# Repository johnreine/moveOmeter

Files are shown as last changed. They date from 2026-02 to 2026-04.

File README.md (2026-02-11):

# moveOmeter

### Privacy-Preserving IoT Monitoring for Elderly Care

> Help your loved ones live independently longer with non-invasive, radar-based health monitoring.






---

## 🎯 The Problem

Families want to care for aging loved ones while respecting their independence and privacy. Traditional monitoring requires cameras (invasive) or wearables (forgotten/rejected).

## 💡 Our Solution

**moveOmeter** uses mmWave radar technology to monitor health and activity patterns without cameras or wearables. The system tracks:

- 🚶 **Activity & Movement** - Daily patterns and mobility changes
- 😴 **Sleep Quality** - Duration, disturbances, and sleep score
- ❤️ **Vital Signs** - Heart rate and respiration (contactless)
- 🚨 **Fall Detection** - Instant alerts for falls or emergencies
- 🏠 **Presence Detection** - Know when they're home or away

**No cameras. No wearables. No user interaction required.**

---

## ✨ Key Features

### Privacy-First Design
- ✅ Radar technology (sees motion, not images)
- ✅ No video, no photos, no recording
- ✅ HIPAA-compliant architecture ready

### Real-Time Monitoring
- ✅ Live web dashboard with charts
- ✅ Mobile-responsive interface
- ✅ Instant WebSocket updates
- ✅ Historical trend analysis

### Smart & Adaptive
- ✅ Learns individual patterns
- ✅ Detects anomalies automatically
- ✅ Over-the-air firmware updates
- ✅ Remote configuration

### Secure & Scalable
- ✅ Role-based access control (admin/employee/caretaker/resident)
- ✅ End-to-end encryption
- ✅ Audit logging
- ✅ Designed to scale to millions of users

---

## 📸 Screenshots

### Real-Time Dashboard
> 🚧 *Screenshot coming soon - see [deployment guide](./deployment/QUICKSTART.md) to run locally*

**Features visible in dashboard:**
- Live timeline charts (1-hour, 12-hour, 24-hour views)
- Activity metrics (movement, presence, sleep quality)
- Device status (online/offline)
- Manual annotations
- Alert notifications

### Admin Panel
> 🚧 *Screenshot coming soon*

**Manage users and devices:**
- User management (create, edit, roles)
- Device assignment
- Access control
- Audit logs

---

## 🚀 Quick Start

### Prerequisites
- ESP32-C6 Feather development board
- DFRobot SEN0623 mmWave sensor
- Supabase account (free tier works)
- Arduino IDE 2.x

### 5-Minute Setup

1. **Clone the repository**
   ```bash
   git clone https://github.com/johnreine/moveOmeter.git
   cd moveOmeter
   ```

2. **Set up database**
   - Create Supabase project at https://supabase.com
   - Run migrations: `database/run_all_migrations.sql`

3. **Configure firmware**
   ```bash
   # Edit pictureFrame/software/mmWave_Supabase_collector/config.h
   # Add your WiFi credentials and Supabase URL/key
   ```

4. **Upload to ESP32-C6**
   - Open Arduino IDE
   - Select board: ESP32C6 Dev Module
   - Upload sketch

5. **Start dashboard**
   ```bash
   cd web/dashboard
   python3 -m http.server 8000
   open http://localhost:8000
   ```

**Full setup guide:** [deployment/QUICKSTART.md](./deployment/QUICKSTART.md)

---

## 🏗️ Architecture

```
┌──────────────────────────────────────────────────────┐
│  ESP32-C6 + mmWave Sensor (DFRobot SEN0623)         │
│  • Collects 40+ health metrics every 20 seconds     │
│  • WiFi upload to cloud                             │
│  • OTA firmware updates                             │
└─────────────────┬────────────────────────────────────┘
                  │ HTTPS Upload
                  ▼
┌──────────────────────────────────────────────────────┐
│  Supabase Backend (PostgreSQL + Auth + Realtime)    │
│  • Time-series sensor data storage                  │
│  • Role-based access control (RLS)                  │
│  • Real-time WebSocket subscriptions                │
│  • OTA firmware distribution                        │
└─────────────────┬────────────────────────────────────┘
                  │ WebSocket + REST API
                  ▼
┌──────────────────────────────────────────────────────┐
│  Web Dashboard (Vanilla JS + Chart.js)              │
│  • Live charts and metrics                          │
│  • User authentication                              │
│  • Admin panel                                      │
│  • Mobile responsive                                │
└──────────────────────────────────────────────────────┘
```

---

## 🛠️ Tech Stack

### Hardware



### Backend



### Frontend




### Firmware



### Deployment



---

## 📚 Documentation

| Document | Description |
|---|---|
| **[Project Status](./PROJECT_STATUS.md)** | Complete overview of features and progress |
| **[Development Roadmap](./ROADMAP.md)** | 6-12 month development plan |
| **[AI Agent Guide](./AI_AGENT_GUIDE.md)** | For AI coding assistants (Claude, GPT, etc.) |
| **[Quick Start](./deployment/QUICKSTART.md)** | Get running in 5 minutes |
| **[Full Deployment Guide](./deployment/README.md)** | Production deployment instructions |
| **[Authentication Setup](./web/dashboard/AUTH_SETUP.md)** | User management and security |
| **[Firmware README](./pictureFrame/software/mmWave_Supabase_collector/README.md)** | ESP32-C6 firmware details |
| **[OTA Testing Guide](./database/OTA_QUICK_TEST.md)** | Test firmware updates |

---

## 🗺️ Roadmap

### ✅ Current (v1.0) - Complete
- ESP32-C6 firmware with dual collection modes
- Real-time web dashboard with charts
- Authentication system (4 user roles)
- Admin panel for user/device management
- OTA firmware update infrastructure
- Timeline annotations
- Data aggregation for performance

### 🚧 Next Month (v1.1)
- [ ] Multi-device support in dashboard
- [ ] Progressive Web App (PWA)
- [ ] Email notifications
- [ ] Activity summary reports
- [ ] Mobile-responsive design improvements

### 🔮 Next Quarter (v1.5)
- [ ] React Native mobile app (iOS + Android)
- [ ] Predictive health alerts (ML-based)
- [ ] Medication reminder integration
- [ ] Voice integration (Alexa/Google Home)
- [ ] Family sharing features

### 🎯 Long-Term Vision
- AI-powered gait analysis and fall risk prediction
- Behavior pattern recognition
- White-label solution for senior living facilities
- Integration ecosystem (Apple Health, etc.)

**Full roadmap:** [ROADMAP.md](./ROADMAP.md)

---

## 🤝 Contributing

We welcome contributions! This project is currently in active development.

### How to Contribute

1. **Read the docs**
   - [Project Status](./PROJECT_STATUS.md) - Current state
   - [Roadmap](./ROADMAP.md) - Planned features
   - [AI Agent Guide](./AI_AGENT_GUIDE.md) - Technical details

2. **Find an issue**
   - Check [Issues](https://github.com/johnreine/moveOmeter/issues) for open tasks
   - Look for `good first issue` or `help wanted` labels

3. **Fork and create a branch**
   ```bash
   git checkout -b feature/your-feature-name
   ```

4. **Make your changes**
   - Follow existing code style
   - Add tests if applicable
   - Update documentation

5. **Submit a pull request**
   - Clear description of changes
   - Reference related issues
   - Screenshots for UI changes

### Development Setup

```bash
# Clone repository
git clone https://github.com/johnreine/moveOmeter.git
cd moveOmeter

# Install Arduino libraries
# - ESPSupabase (by jhagas)
# - DFRobot_HumanDetection (by DFRobot)

# Set up Supabase
# 1. Create account at https://supabase.com
# 2. Run database/run_all_migrations.sql

# Start local dashboard
cd web/dashboard
python3 -m http.server 8000
```

### Code Style

- **JavaScript:** ES6+, async/await, template literals
- **C++:** Arduino style, comments for complex logic
- **SQL:** Uppercase keywords, clear comments
- **Documentation:** Markdown with clear headings

---

## 🌟 Use Cases

### For Families
- Monitor aging parents remotely
- Peace of mind while at work
- Early detection of health changes
- Respect privacy (no cameras)

### For Caregivers
- Track multiple clients
- Shift handoff notes
- Medication reminders
- Fall alerts

### For Senior Living Facilities
- Monitor all residents
- Staff coordination
- Compliance reporting
- Emergency response

### For Healthcare Providers
- Remote patient monitoring
- Post-discharge tracking
- Chronic condition management
- Reduce hospital readmissions

---

## 📊 Project Stats

- **40 files** of comprehensive documentation
- **16,000+ lines** of code and docs
- **40+ sensor metrics** collected
- **4 user roles** with granular permissions
- **3 timeline views** (1h, 12h, 24h)
- **97% bandwidth reduction** with smart keep-alive
- **OTA updates** for remote firmware deployment

---

## 🔐 Security & Privacy

### Privacy Protections
- ✅ No cameras or video recording
- ✅ Radar technology (motion only, not images)
- ✅ Data encrypted in transit (HTTPS)
- ✅ Data encrypted at rest (Supabase)
- ✅ Row Level Security (RLS) for data isolation

### Compliance Ready
- 🔜 HIPAA compliance architecture
- 🔜 GDPR data handling
- 🔜 SOC 2 Type II準備中

### Security Features
- Multi-factor authentication (MFA) support
- Passkey/WebAuthn ready
- Audit logging for all actions
- Role-based access control
- Automatic session management

---

## 🛡️ Testing

### Current Test Coverage
- ✅ End-to-end firmware testing
- ✅ Real-time data pipeline
- ✅ Authentication flows
- ✅ Role-based access control
- 🚧 Cross-browser compatibility
- 🚧 Scale testing (100-1000 devices)

### Tested Environments
- **Firmware:** ESP32-C6 Feather
- **Browsers:** Chrome, Firefox, Safari (desktop)
- **Database:** Supabase (PostgreSQL 15)
- **Deployment:** Ubuntu 22.04 + Nginx

---

## 💰 Cost to Run

### Development (Current)
- **Supabase:** Free tier (good for 10 devices)
- **Digital Ocean:** $10-20/month
- **Total:** ~$10-20/month

### Small Deployment (100 devices)
- **Supabase:** $25/month (Pro tier)
- **Digital Ocean:** $20/month
- **Total:** ~$45/month

### Medium Scale (1,000 devices)
- **Supabase:** $599/month (Team tier)
- **Digital Ocean/AWS:** $100-200/month
- **Total:** ~$700-800/month

**Note:** Costs scale linearly. See [ROADMAP.md](./ROADMAP.md) for scaling details.

---

## 📄 License

**Proprietary** - All rights reserved.

This project is currently not open source. Contact for licensing inquiries.

---

## 📞 Contact & Support

### Questions or Issues?
1. Check [Project Status](./PROJECT_STATUS.md) and [Roadmap](./ROADMAP.md)
2. Review [documentation](./deployment/README.md)
3. Open an [Issue](https://github.com/johnreine/moveOmeter/issues)

### Business Inquiries
- **Email:** contact@moveometer.com (TBD)
- **Website:** https://moveometer.com (TBD)

### For Contributors
- Join discussions in [Issues](https://github.com/johnreine/moveOmeter/issues)
- Submit [Pull Requests](https://github.com/johnreine/moveOmeter/pulls)
- See [AI Agent Guide](./AI_AGENT_GUIDE.md) for technical details

---

## 🙏 Acknowledgments

### Hardware
- **Adafruit** - ESP32-C6 Feather development board
- **DFRobot** - SEN0623 mmWave sensor

### Software & Services
- **Supabase** - Backend-as-a-Service platform
- **Chart.js** - Beautiful data visualization
- **Arduino** - ESP32 development framework

### Inspiration
Built with care for families supporting elderly loved ones. Inspired by the need for privacy-preserving health monitoring that maintains dignity and independence.

---

## ⭐ Star History

If you find this project useful, consider giving it a star! ⭐

---

## 📈 Project Activity




---

<div align="center">

**Made with ❤️ for better elderly care**

[Documentation](./PROJECT_STATUS.md) • [Roadmap](./ROADMAP.md) • [Contributing](#contributing) • [License](#license)

</div>

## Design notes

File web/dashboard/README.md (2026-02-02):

# moveOmeter Real-Time Dashboard

Beautiful web-based dashboard for visualizing mmWave sensor data in real-time.

## Features

- 📊 **Live Charts** - Heart rate, respiration, presence, and sleep quality
- 🔴 **Real-Time Updates** - Automatic updates via Supabase Realtime
- ⚠️ **Alerts** - Visual warnings for apnea events, struggles, and unusual activity
- 📱 **Responsive Design** - Works on desktop, tablet, and mobile
- 🎨 **Beautiful UI** - Modern gradient design with smooth animations

## Quick Start

### Option 1: Simple File Open (Easiest)

1. Open `index.html` directly in your web browser:
   ```bash
   open index.html
   ```
   Or just double-click `index.html` in Finder

2. The dashboard will connect to your Supabase database automatically

**Note:** Real-time updates might not work with `file://` protocol. Use Option 2 for full functionality.

### Option 2: Local Web Server (Recommended)

Using Python 3:
```bash
cd /Users/johnreine/Dropbox/john/2025_work/moveOmeter/web/dashboard
python3 -m http.server 8000
```

Then open: http://localhost:8000

### Option 3: Using Node.js

```bash
npx http-server -p 8000
```

Then open: http://localhost:8000

## Configuration

Edit `config.js` to customize:

```javascript
// Device to monitor (set to null to show all devices)
deviceId: 'ESP32C6_001',

// How often to refresh data (milliseconds)
refreshInterval: 5000,

// Number of data points to show in charts
maxDataPoints: 20
```

## Dashboard Sections

### Current Metrics (Top Cards)
- **Heart Rate** - Real-time heart rate in BPM
- **Respiration** - Breaths per minute
- **Presence** - Is person detected?
- **In Bed** - Current bed occupancy
- **Sleep Quality** - Overall sleep quality score (0-100)
- **Apnea Events** - Count of breathing pause events

### Charts
1. **Heart Rate** - Line chart showing heart rate over last 20 readings
2. **Respiration Rate** - Breathing pattern visualization
3. **Presence & Movement** - Dual-axis chart showing detection and movement intensity
4. **Sleep Quality** - Bar chart of sleep quality scores over time

### Alerts
Automatic alerts appear for:
- 🚨 Apnea events (breathing stopped)
- ⚠️ Abnormal struggle detected
- 🛏️ Out of bed during night hours (10pm-6am)
- 👤 Person left monitored area

## Real-Time Updates

The dashboard uses **Supabase Realtime** to automatically update when new data arrives from your ESP32-C6 device. No page refresh needed!

How it works:
1. ESP32-C6 inserts new row into Supabase table
2. Supabase broadcasts change via WebSocket
3. Dashboard receives update instantly
4. Charts and metrics update automatically

## Troubleshooting

### Dashboard shows "Disconnected"
- Check that Supabase URL and anon key are correct in `config.js`
- Verify the table name matches your database
- Check browser console (F12) for error messages

### No data appears
- Verify ESP32-C6 is running and uploading data
- Check Supabase table has data: `SELECT * FROM mmwave_sensor_data LIMIT 10;`
- Confirm `deviceId` in `config.js` matches your device

### Charts not updating
- Ensure you're using a web server (Option 2 or 3), not `file://`
- Check browser console for WebSocket connection errors
- Try refreshing the page

### Real-time not working
- Supabase Realtime requires Row Level Security to be properly configured
- Verify the table has RLS policies allowing reads
- Check your Supabase project has Realtime enabled

## Customization

### Change Color Scheme
Edit the CSS in `index.html`:
```css
background: linear-gradient(135deg, #667eea 0%, #764ba2 100%);
```

### Add More Charts
1. Add a new canvas element in `index.html`:
   ```html
   <canvas id="myNewChart"></canvas>
   ```

2. Initialize the chart in `dashboard.js`:
   ```javascript
   charts.myNew = new Chart(document.getElementById('myNewChart'), {
       // Chart configuration
   });
   ```

3. Update the chart in the `updateCharts()` function

### Modify Alert Conditions
Edit the `checkAlerts()` function in `dashboard.js` to add custom alert logic.

## Deployment

### Deploy to Static Hosting

**Netlify:**
```bash
# Install Netlify CLI
npm install -g netlify-cli

# Deploy
cd /Users/johnreine/Dropbox/john/2025_work/moveOmeter/web/dashboard
netlify deploy --prod
```

**Vercel:**
```bash
# Install Vercel CLI
npm install -g vercel

# Deploy
cd /Users/johnreine/Dropbox/john/2025_work/moveOmeter/web/dashboard
vercel --prod
```

**GitHub Pages:**
1. Create a GitHub repository
2. Push the `web/dashboard` folder
3. Enable GitHub Pages in repository settings

### Security Considerations

⚠️ **IMPORTANT:** The `config.js` file contains your Supabase anon key. This is safe for client-side use, but:

1. **Enable Row Level Security (RLS)** on your Supabase table
2. **Never use the service_role key** in client-side code
3. For production, consider using environment variables with a build step

## Performance Tips

- **Reduce `maxDataPoints`** if charts feel sluggish (try 10-15)
- **Increase `refreshInterval`** if you don't need sub-second updates
- **Use specific `deviceId`** to filter data for better performance

## Browser Support

Works on all modern browsers:
- ✅ Chrome/Edge (recommended)
- ✅ Firefox
- ✅ Safari
- ✅ Mobile browsers (iOS Safari, Chrome Mobile)

Requires JavaScript enabled.

## Next Steps

1. **Add authentication** - Require login to view dashboard
2. **Historical data view** - Add date picker to view past data
3. **Export functionality** - Download data as CSV/PDF
4. **Mobile app** - Convert to React Native or Flutter app
5. **Notifications** - Add push notifications for critical alerts

## Files

- `index.html` - Main dashboard page
- `dashboard.js` - Chart logic and data fetching
- `config.js` - Configuration (Supabase credentials)
- `README.md` - This file

## License

Part of the moveOmeter IoT elderly monitoring project.

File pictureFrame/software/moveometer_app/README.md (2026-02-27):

# moveometer_app

A new Flutter project.

## Getting Started

This project is a starting point for a Flutter application.

A few resources to get you started if this is your first Flutter project:

- [Lab: Write your first Flutter app](https://docs.flutter.dev/get-started/codelab)
- [Cookbook: Useful Flutter samples](https://docs.flutter.dev/cookbook)

For help getting started with Flutter development, view the
[online documentation](https://docs.flutter.dev/), which offers tutorials,
samples, guidance on mobile development, and a full API reference.

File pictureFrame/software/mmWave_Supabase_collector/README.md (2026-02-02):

# mmWave Supabase Data Collector

Complete IoT solution for collecting mmWave sensor data and uploading to Supabase in real-time.

## Features

- ✅ Collects 40+ data fields from SEN0623 mmWave sensor
- ✅ WiFi connectivity with auto-reconnect
- ✅ Direct upload to Supabase using ESPSupabase library
- ✅ Automatic retry logic for failed uploads
- ✅ JSON formatted data
- ✅ Configurable collection intervals
- ✅ Sleep Mode optimized for elderly monitoring

## Quick Start

### 1. Install Required Libraries

Open Arduino IDE → Tools → Manage Libraries, then install:
- **ESPSupabase** by jhagas
- **DFRobot_HumanDetection** by DFRobot

### 2. Configure Your Settings

Edit `config.h` and set:

```cpp
// WiFi credentials
#define WIFI_SSID "your_wifi_network"
#define WIFI_PASSWORD "your_wifi_password"

// Supabase settings (from your Supabase dashboard)
#define SUPABASE_URL "https://xxxxx.supabase.co"
#define SUPABASE_ANON_KEY "eyJhbGc..."

// Database table name
#define SUPABASE_TABLE "mmwave_sensor_data"

// Device identification
#define DEVICE_ID "ESP32C6_001"
#define LOCATION "bedroom_1"
```

### 3. Create Supabase Table

In your Supabase dashboard, run this SQL:

```sql
CREATE TABLE mmwave_sensor_data (
  id BIGSERIAL PRIMARY KEY,
  created_at TIMESTAMPTZ DEFAULT NOW(),

  -- Metadata
  device_id TEXT NOT NULL,
  location TEXT,
  uptime_sec INTEGER,

  -- Human Presence & Movement
  human_presence INTEGER,
  human_movement INTEGER,
  moving_range INTEGER,
  distance_cm INTEGER,

  -- Vital Signs
  heart_rate_bpm INTEGER,
  respiration_rate INTEGER,
  respiration_state INTEGER,

  -- Sleep Status
  in_bed INTEGER,
  sleep_state INTEGER,
  wake_duration_min INTEGER,
  light_sleep_min INTEGER,
  deep_sleep_min INTEGER,
  sleep_quality INTEGER,
  sleep_disturbances INTEGER,
  sleep_quality_rating INTEGER,

  -- Abnormal Events
  abnormal_struggle INTEGER,
  unattended_state INTEGER,

  -- Sleep Composite Data
  composite_presence INTEGER,
  composite_sleep_state INTEGER,
  composite_avg_respiration INTEGER,
  composite_avg_heartbeat INTEGER,
  composite_turnover_count INTEGER,
  composite_large_body_move_pct INTEGER,
  composite_minor_body_move_pct INTEGER,
  composite_apnea_events INTEGER,

  -- Sleep Statistics
  stats_sleep_quality_score INTEGER,
  stats_sleep_time_min INTEGER,
  stats_wake_duration_min INTEGER,
  stats_shallow_sleep_pct INTEGER,
  stats_deep_sleep_pct INTEGER,
  stats_time_out_of_bed_min INTEGER,
  stats_exit_count INTEGER,
  stats_turnover_count INTEGER,
  stats_avg_respiration INTEGER,
  stats_avg_heartbeat INTEGER,
  stats_apnea_events INTEGER
);

-- Create indexes for better query performance
CREATE INDEX idx_device_created ON mmwave_sensor_data(device_id, created_at DESC);
CREATE INDEX idx_location ON mmwave_sensor_data(location);
CREATE INDEX idx_presence ON mmwave_sensor_data(human_presence, created_at DESC);
```

### 4. Get Your Supabase Credentials

1. Go to your Supabase project dashboard
2. Click **Settings** → **API**
3. Copy:
   - **Project URL** → paste into `SUPABASE_URL`
   - **anon/public key** → paste into `SUPABASE_ANON_KEY`

### 5. Upload and Run

1. Connect ESP32-C6 to your computer
2. Select board: **ESP32C6 Dev Module**
3. Select port
4. Upload the sketch
5. Open Serial Monitor at 115200 baud

## Expected Output

```
=================================
mmWave Supabase Data Collector
=================================
Connecting to WiFi: MyNetwork... CONNECTED!
IP Address: 192.168.1.100
Initializing Supabase... SUCCESS!
Initializing sensor (this takes ~10 seconds)... SUCCESS!
Configuring Sleep Mode... SUCCESS!
=================================
System ready! Collecting data...

Data collected:
{"device_id":"ESP32C6_001","location":"bedroom_1",...}
Uploading to Supabase... SUCCESS!
```

## Data Fields Reference

### Vital Signs
- **heart_rate_bpm**: Heart rate in beats per minute (0-255)
- **respiration_rate**: Breaths per minute (0-255)
- **respiration_state**: 1=normal, 2=too fast, 3=too slow, 4=none

### Sleep Metrics
- **in_bed**: 0=out of bed, 1=in bed
- **sleep_state**: Current sleep state code
- **sleep_quality**: Real-time sleep quality score
- **stats_sleep_quality_score**: Overall sleep quality (cumulative)
- **stats_sleep_time_min**: Total sleep duration in minutes
- **stats_shallow_sleep_pct**: Light sleep as percentage of total
- **stats_deep_sleep_pct**: Deep sleep as percentage of total

### Movement Detection
- **human_presence**: 0=absent, 1=present
- **human_movement**: Movement intensity (0-100)
- **moving_range**: Movement area coverage (0-100)
- **distance_cm**: Distance to detected person in centimeters

### Abnormal Events
- **abnormal_struggle**: Detected struggle or distress
- **composite_apnea_events**: Breathing pause events (sleep apnea)
- **stats_apnea_events**: Total apnea events (cumulative)
- **unattended_state**: Person has left the monitored area

### Sleep Analysis
- **composite_turnover_count**: Number of position changes
- **composite_large_body_move_pct**: Large movements as percentage
- **composite_minor_body_move_pct**: Small movements as percentage
- **stats_exit_count**: Times person got out of bed
- **stats_time_out_of_bed_min**: Total time spent out of bed

## Configuration Options

### Data Collection Interval

In `config.h`, adjust:
```cpp
#define DATA_INTERVAL 5000  // milliseconds (5 seconds default)
```

Recommendations:
- Real-time monitoring: 1000-5000 ms
- Battery optimization: 30000-60000 ms
- Long-term trends: 300000-900000 ms (5-15 minutes)

### Retry Settings

```cpp
#define RETRY_ATTEMPTS 3     // Number of upload retries
#define RETRY_DELAY 2000     // Delay between retries (ms)
```

## Troubleshooting

### WiFi Connection Failed
- Verify SSID and password in `config.h`
- Check that ESP32-C6 is within WiFi range
- Ensure 2.4GHz WiFi (ESP32-C6 doesn't support 5GHz)

### Supabase Upload Failed (HTTP 401)
- Check that `SUPABASE_ANON_KEY` is correct
- Verify table name matches `SUPABASE_TABLE`
- Check Supabase Row Level Security policies (disable for testing)

### Supabase Upload Failed (HTTP 404)
- Table name doesn't exist
- Check `SUPABASE_TABLE` spelling in `config.h`

### Sensor Initialization Failed
- Check wiring connections
- Verify 5V power supply
- Wait 10 seconds for sensor startup

### Data Looks Wrong
- Sensor needs ~30-60 seconds after startup to calibrate
- Movement data is only accurate when person is in detection range
- Sleep statistics accumulate over time (won't show immediately)

## Security Best Practices

### Protect Your Credentials

**IMPORTANT**: Never commit `config.h` to public repositories!

Add to `.gitignore`:
```
config.h
```

### Supabase Row Level Security

For production, enable RLS policies in Supabase:

```sql
-- Allow inserts from authenticated devices only
ALTER TABLE mmwave_sensor_data ENABLE ROW LEVEL SECURITY;

CREATE POLICY "Allow device inserts"
ON mmwave_sensor_data
FOR INSERT
WITH CHECK (auth.role() = 'anon');

-- Allow reads for authenticated users
CREATE POLICY "Allow authenticated reads"
ON mmwave_sensor_data
FOR SELECT
USING (auth.role() = 'authenticated');
```

## Next Steps

1. **Multiple Devices**: Clone and configure unique `DEVICE_ID` for each unit
2. **Data Visualization**: Build dashboards in Supabase or connect to Grafana
3. **Alerts**: Create edge functions to send notifications for abnormal events
4. **Battery Operation**: Add deep sleep between readings for battery power
5. **OTA Updates**: Implement over-the-air firmware updates

## Hardware Requirements

- ESP32-C6 Feather (or compatible board)
- DF Robot SEN0623 (C1001 mmWave sensor)
- 5V power supply (USB or dedicated)
- WiFi network (2.4GHz)

## Libraries Used

- **ESPSupabase** - [GitHub](https://github.com/jhagas/ESPSupabase)
- **DFRobot_HumanDetection** - [GitHub](https://github.com/DFRobot/DFRobot_HumanDetection)

## License

This is part of the moveOmeter IoT elderly monitoring project.

## Support

For issues or questions, refer to:
- [ESPSupabase Documentation](https://github.com/jhagas/ESPSupabase)
- [SEN0623 Wiki](https://wiki.dfrobot.com/SKU_SEN0623_C1001_mmWave_Human_Detection_Sensor)

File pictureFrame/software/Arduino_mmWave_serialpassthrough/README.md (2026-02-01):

# Arduino mmWave Serial Passthrough

Simple serial passthrough program for ESP32-C6 Feather to communicate with the DF Robot SEN0623 (C1001 mmWave Human Detection system).

## Purpose

This test program allows you to:
- View raw data from the mmWave sensor on your computer
- Send configuration commands to the mmWave sensor
- Verify the sensor is working correctly before integration

## Hardware Connections

Connect the DF Robot SEN0623 to the ESP32-C6 Feather:

| mmWave Sensor | ESP32-C6 Feather |
|---|---|
| TX | GPIO17 (RX) |
| RX | GPIO16 (TX) |
| GND | GND |
| VCC | 3.3V or 5V |

**Note:** Check the SEN0623 datasheet for proper voltage (3.3V or 5V).

## How to Use

1. **Upload the sketch**
   - Open `Arduino_mmWave_serialpassthrough.ino` in Arduino IDE
   - Select board: "ESP32C6 Dev Module" or "Adafruit Feather ESP32-C6"
   - Select the correct COM port
   - Click Upload

2. **Open Serial Monitor**
   - Set baud rate to **115200**
   - You should see the startup message
   - Data from the mmWave sensor will appear in the monitor

3. **Send commands to sensor**
   - Type commands in the Serial Monitor input field
   - Commands will be forwarded to the mmWave sensor
   - Sensor responses will appear in the monitor

## Configuration

If the mmWave sensor uses a different baud rate:
- Edit `MMWAVE_BAUD` in the sketch (line 27)
- Common values: 9600, 115200, 256000

## Troubleshooting

**No data appearing:**
- Check wiring connections
- Verify sensor power (LED should be on if present)
- Try different baud rates for MMWAVE_BAUD
- Confirm TX/RX are not swapped

**Garbled data:**
- Wrong baud rate - check sensor documentation
- Possible wiring issue or loose connection

**Cannot upload sketch:**
- Press and hold BOOT button while uploading
- Check USB cable supports data (not just charging)
- Verify correct board and port selected in Arduino IDE

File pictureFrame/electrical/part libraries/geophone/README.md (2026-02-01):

# SM-24 Geophone Front-End with ADS1220 ADC

## Circuit Overview

```
                                    +3.3V
                                      │
                                     ┌┴┐
                                R1   │ │ 100k
                                     └┬┘
     ┌─────────┐                      │
     │  SM-24  │    C1        VCC/2   │        R4 (100k)
     │ Geophone├────┤├────┬────●──────┼────────/\/\/────┐
     │         │  10µF    │           │                  │
     └────┬────┘         ┌┴┐          │    ┌─────┐       │
          │         R1   │ │ 100k     └────┤-  U1A├──────┴───┐
         GND             └┬┘               │  OPA │          │
                          │          ┌─────┤+    │          │
                         ┌┴┐         │     └─────┘          │
                    C2   │ │ 10µF    │                      │
                         └┬┘       VCC/2                    │
                          │          │                      │
                         GND        ┌┴┐                     │
                                R3  │ │ 1k                  │
                                    └┬┘                     │
                                     │                      │
                                    GND                     │
                                                            │
    ┌───────────────────────────────────────────────────────┘
    │
    │  Sallen-Key Low-Pass Filter (50Hz)
    │
    │     R5          R6
    └────/\/\/───┬───/\/\/───┬─────────┤+  U1B ├────┬─────► To ADC
        31.6k   │   31.6k   │         │  OPA  │    │       (AIN0)
               ┌┴┐         ┌┴┐   ┌────┤-     │    │
          C3   │ │100nF    │ │   │    └──────┘    │
               └┬┘         └┬┘   │                │
                │    C4     │    └────────────────┘
               GND        GND

    ADS1220 ADC Connections:
    ┌──────────────────────────────────────────┐
    │  ADS1220                                 │
    │                                          │
    │  AIN0 ◄──── Filter Output               │
    │  AIN1 ◄──── GND (differential ref)      │
    │                                          │
    │  REFP0 ◄─── AVDD (internal 2.048V ref)  │
    │  REFN0 ◄─── GND                         │
    │                                          │
    │  AVDD ◄──── +3.3V                       │
    │  DVDD ◄──── +3.3V                       │
    │  AVSS ◄──── GND                         │
    │  DGND ◄──── GND                         │
    │                                          │
    │  SCLK ────► MCU SPI Clock               │
    │  DOUT ────► MCU MISO                    │
    │  DIN  ◄──── MCU MOSI                    │
    │  CS   ◄──── MCU Chip Select             │
    │  DRDY ────► MCU (interrupt, optional)   │
    └──────────────────────────────────────────┘
```

## Design Parameters

| Parameter | Value | Notes |
|---|---|---|
| Supply Voltage | 3.3V | Single supply |
| First Stage Gain | 101x (40.1 dB) | 1 + R4/R3 = 1 + 100k/1k |
| Filter Cutoff | ~50 Hz | Sallen-Key 2nd order |
| Filter Q | 0.707 | Butterworth response |
| ADC Resolution | 24 bits | ADS1220 with PGA |
| Sample Rate | Up to 2000 SPS | Configurable |

## Bill of Materials

| Ref | Value | Package | Description | DigiKey P/N |
|-----|---|---|---|---|
| U1 | OPA2188 | SOIC-8 | Low-noise dual op-amp | 296-40058-1-ND |
| U2 | ADS1220 | TSSOP-16 | 24-bit delta-sigma ADC | 296-35377-1-ND |
| C1 | 10µF | 0805 | Input coupling | 1276-1096-1-ND |
| C2 | 10µF | 0805 | Bias bypass | 1276-1096-1-ND |
| C3 | 100nF | 0603 | Filter capacitor | 1276-1005-1-ND |
| C4 | 100nF | 0603 | Filter capacitor | 1276-1005-1-ND |
| C5 | 100µF | 1206 | Power supply bulk | 1276-6767-1-ND |
| C6 | 100nF | 0603 | Op-amp bypass | 1276-1005-1-ND |
| C7 | 100nF | 0603 | ADC AVDD bypass | 1276-1005-1-ND |
| C8 | 100nF | 0603 | ADC DVDD bypass | 1276-1005-1-ND |
| R1 | 100k | 0603 | Bias divider (top) | 311-100KHRCT-ND |
| R2 | 100k | 0603 | Bias divider (bottom) | 311-100KHRCT-ND |
| R3 | 1k | 0603 | Gain set resistor | 311-1.00KHRCT-ND |
| R4 | 100k | 0603 | Feedback resistor | 311-100KHRCT-ND |
| R5 | 31.6k | 0603 | Filter resistor | 311-31.6KHRCT-ND |
| R6 | 31.6k | 0603 | Filter resistor | 311-31.6KHRCT-ND |
| J1 | 1x2 | 2.54mm | Geophone connector | 952-2261-ND |
| J2 | 1x6 | 2.54mm | SPI connector | 952-2265-ND |
| J3 | 1x2 | 2.54mm | Power connector | 952-2261-ND |

## SPI Connector Pinout (J2)

| Pin | Signal | Description |
|-----|---|---|
| 1 | VCC | 3.3V supply |
| 2 | SCLK | SPI clock |
| 3 | MISO | SPI data out (DOUT) |
| 4 | MOSI | SPI data in (DIN) |
| 5 | CS | Chip select (active low) |
| 6 | GND | Ground |

## Component Selection Notes

### Op-Amp (OPA2188)
- Very low offset voltage (±25µV max)
- Low noise (8.8 nV/√Hz)
- Rail-to-rail output
- Alternatives: MCP6022 (cheaper), OPA1612 (lower noise)

### ADC (ADS1220)
- 24-bit resolution
- Built-in PGA (gains 1, 2, 4, 8, 16, 32, 64, 128)
- Internal 2.048V reference
- Up to 2000 SPS
- Differential inputs reduce common-mode noise

### Filter Component Calculations
For a 50Hz Butterworth low-pass filter with Q = 0.707:
```
fc = 1 / (2π × R × C × √2)
With R5 = R6 = 31.6k and C3 = C4 = 100nF:
fc = 1 / (2π × 31.6k × 100nF × 1.414) ≈ 50 Hz
```

## Arduino/ESP32 Code Example

```cpp
#include <SPI.h>

// ADS1220 registers and commands
#define ADS1220_CMD_RESET    0x06
#define ADS1220_CMD_START    0x08
#define ADS1220_CMD_RDATA    0x10
#define ADS1220_CMD_RREG     0x20
#define ADS1220_CMD_WREG     0x40

const int CS_PIN = 10;
const int DRDY_PIN = 9;

void setup() {
  Serial.begin(115200);
  SPI.begin();
  pinMode(CS_PIN, OUTPUT);
  pinMode(DRDY_PIN, INPUT);
  digitalWrite(CS_PIN, HIGH);
  
  // Reset ADS1220
  digitalWrite(CS_PIN, LOW);
  SPI.transfer(ADS1220_CMD_RESET);
  digitalWrite(CS_PIN, HIGH);
  delay(1);
  
  // Configure: AIN0/AIN1 differential, gain=1, 20SPS, internal ref
  digitalWrite(CS_PIN, LOW);
  SPI.transfer(ADS1220_CMD_WREG | 0x00); // Write starting at reg 0
  SPI.transfer(0x04);  // 4 bytes to write
  SPI.transfer(0x01);  // Reg0: AIN0/AIN1, gain=1, PGA enabled
  SPI.transfer(0x04);  // Reg1: 20 SPS, normal mode
  SPI.transfer(0x40);  // Reg2: Internal 2.048V reference
  SPI.transfer(0x00);  // Reg3: Default
  digitalWrite(CS_PIN, HIGH);
  
  // Start continuous conversion
  digitalWrite(CS_PIN, LOW);
  SPI.transfer(ADS1220_CMD_START);
  digitalWrite(CS_PIN, HIGH);
}

void loop() {
  // Wait for data ready
  while (digitalRead(DRDY_PIN) == HIGH);
  
  // Read 24-bit result
  digitalWrite(CS_PIN, LOW);
  SPI.transfer(ADS1220_CMD_RDATA);
  int32_t result = 0;
  result |= ((int32_t)SPI.transfer(0x00) << 16);
  result |= ((int32_t)SPI.transfer(0x00) << 8);
  result |= SPI.transfer(0x00);
  digitalWrite(CS_PIN, HIGH);
  
  // Sign extend 24-bit to 32-bit
  if (result & 0x800000) {
    result |= 0xFF000000;
  }
  
  // Convert to voltage (with 2.048V reference, gain=1)
  float voltage = (float)result * 2.048 / 8388608.0;
  
  Serial.println(voltage, 6);
  delay(50);  // ~20 Hz sample rate
}
```

## PCB Layout Tips

1. **Ground plane**: Use a solid ground plane on bottom layer
2. **Analog/digital separation**: Keep digital traces away from analog input
3. **Decoupling caps**: Place as close to IC pins as possible
4. **Input traces**: Keep short, away from digital signals
5. **Via placement**: Avoid vias in analog signal path
6. **Component placement**: Place in signal flow order (left to right)

## Adjustments for Your Application

**Higher sensitivity (weak signals):**
- Increase R4 to 220k for gain of ~221x (47 dB)
- Add second gain stage if needed

**Lower cutoff frequency (slower gait):**
- Increase R5, R6 to 68k for ~25 Hz cutoff
- Or increase C3, C4 to 220nF

**Higher sample rate:**
- Configure ADS1220 for 330 SPS or higher
- May need to adjust filter cutoff accordingly

**Battery operation:**
- OPA2188 has low quiescent current (~400µA)
- ADS1220 duty cycle mode for power savings

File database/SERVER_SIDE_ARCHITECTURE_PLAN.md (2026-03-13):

# Server-Side Architecture Plan
## Moving All Logic from Clients to Database

**Problem:** Clients (web dashboard and mobile app) are currently doing extensive data processing, status calculations, and business logic. This causes inconsistencies, bugs, and violates the principle that clients should just display data.

**Goal:** Move ALL logic to the server. Clients become read-only displays of pre-computed database values.

---

## Phase 1: Device Status Tracking

### 1.1 Database Schema Changes

**Add columns to `moveometers` table:**
```sql
ALTER TABLE moveometers ADD COLUMN IF NOT EXISTS
    connection_status VARCHAR(20) DEFAULT 'unknown', -- 'online', 'stale', 'offline', 'unknown'
    connection_status_updated_at TIMESTAMPTZ,
    seconds_since_last_data INTEGER,
    connection_quality_score INTEGER DEFAULT 0, -- 0-100
    last_data_received_at TIMESTAMPTZ; -- Auto-updated on each data insert
```

**Create device status history table:**
```sql
CREATE TABLE IF NOT EXISTS device_status_history (
    id UUID PRIMARY KEY DEFAULT gen_random_uuid(),
    device_id TEXT REFERENCES moveometers(device_id),
    status VARCHAR(20) NOT NULL, -- 'online', 'stale', 'offline'
    started_at TIMESTAMPTZ NOT NULL,
    ended_at TIMESTAMPTZ,
    duration_seconds INTEGER,
    created_at TIMESTAMPTZ DEFAULT NOW()
);

CREATE INDEX idx_device_status_history_device ON device_status_history(device_id, started_at DESC);
```

### 1.2 Database Function: Update Device Status

**Function runs on every data insert via trigger:**
```sql
CREATE OR REPLACE FUNCTION update_device_status()
RETURNS TRIGGER AS $$
DECLARE
    v_seconds_since_last INTEGER;
    v_new_status VARCHAR(20);
    v_old_status VARCHAR(20);
BEGIN
    -- Calculate seconds since last data
    v_seconds_since_last := EXTRACT(EPOCH FROM (NOW() - COALESCE(NEW.device_timestamp, NEW.created_at)));

    -- Determine new status based on thresholds
    IF v_seconds_since_last <= 20 THEN
        v_new_status := 'online';
    ELSIF v_seconds_since_last <= 60 THEN
        v_new_status := 'stale';
    ELSE
        v_new_status := 'offline';
    END IF;

    -- Get current status
    SELECT connection_status INTO v_old_status
    FROM moveometers
    WHERE device_id = NEW.device_id;

    -- Update device status
    UPDATE moveometers SET
        connection_status = v_new_status,
        connection_status_updated_at = NOW(),
        seconds_since_last_data = v_seconds_since_last,
        last_data_received_at = COALESCE(NEW.device_timestamp, NEW.created_at),
        connection_quality_score = CASE
            WHEN v_seconds_since_last <= 20 THEN 100
            WHEN v_seconds_since_last <= 60 THEN 70
            ELSE 0
        END
    WHERE device_id = NEW.device_id;

    -- Record status change in history
    IF v_old_status IS DISTINCT FROM v_new_status THEN
        -- End previous status period
        UPDATE device_status_history
        SET ended_at = NOW(),
            duration_seconds = EXTRACT(EPOCH FROM (NOW() - started_at))
        WHERE device_id = NEW.device_id
            AND ended_at IS NULL;

        -- Start new status period
        INSERT INTO device_status_history (device_id, status, started_at)
        VALUES (NEW.device_id, v_new_status, NOW());
    END IF;

    RETURN NEW;
END;
$$ LANGUAGE plpgsql;

-- Attach trigger to sensor data inserts
CREATE TRIGGER trigger_update_device_status
    AFTER INSERT ON mmwave_sensor_data
    FOR EACH ROW
    EXECUTE FUNCTION update_device_status();
```

### 1.3 Scheduled Job: Check for Stale Devices

**Runs every 30 seconds to update devices that haven't sent data:**
```sql
CREATE OR REPLACE FUNCTION check_stale_devices()
RETURNS void AS $$
DECLARE
    v_device RECORD;
    v_seconds_since_last INTEGER;
    v_new_status VARCHAR(20);
BEGIN
    FOR v_device IN
        SELECT device_id, connection_status, last_data_received_at
        FROM moveometers
        WHERE device_status = 'active'
    LOOP
        v_seconds_since_last := EXTRACT(EPOCH FROM (NOW() - v_device.last_data_received_at));

        IF v_seconds_since_last <= 20 THEN
            v_new_status := 'online';
        ELSIF v_seconds_since_last <= 60 THEN
            v_new_status := 'stale';
        ELSE
            v_new_status := 'offline';
        END IF;

        -- Only update if status changed
        IF v_device.connection_status IS DISTINCT FROM v_new_status THEN
            UPDATE moveometers SET
                connection_status = v_new_status,
                connection_status_updated_at = NOW(),
                seconds_since_last_data = v_seconds_since_last
            WHERE device_id = v_device.device_id;

            -- Update history
            UPDATE device_status_history
            SET ended_at = NOW(),
                duration_seconds = EXTRACT(EPOCH FROM (NOW() - started_at))
            WHERE device_id = v_device.device_id
                AND ended_at IS NULL;

            INSERT INTO device_status_history (device_id, status, started_at)
            VALUES (v_device.device_id, v_new_status, NOW());
        END IF;
    END LOOP;
END;
$$ LANGUAGE plpgsql;

-- Schedule via pg_cron or Supabase scheduled function (runs every 30 seconds)
SELECT cron.schedule(
    'check-stale-devices',
    '*/30 * * * * *', -- Every 30 seconds
    'SELECT check_stale_devices();'
);
```

---

## Phase 2: Pre-compute Offline Periods

### 2.1 Create Offline Periods View

**Materialized view or table with offline periods:**
```sql
CREATE TABLE IF NOT EXISTS device_offline_periods (
    id UUID PRIMARY KEY DEFAULT gen_random_uuid(),
    device_id TEXT REFERENCES moveometers(device_id),
    offline_start TIMESTAMPTZ NOT NULL,
    offline_end TIMESTAMPTZ,
    duration_seconds INTEGER,
    is_ongoing BOOLEAN DEFAULT false,
    created_at TIMESTAMPTZ DEFAULT NOW()
);

CREATE INDEX idx_offline_periods_device ON device_offline_periods(device_id, offline_start DESC);
```

### 2.2 Function to Track Offline Periods

**Auto-populated from device_status_history:**
```sql
CREATE OR REPLACE FUNCTION sync_offline_periods()
RETURNS void AS $$
BEGIN
    -- Close ongoing offline periods that have ended
    UPDATE device_offline_periods
    SET offline_end = h.ended_at,
        duration_seconds = h.duration_seconds,
        is_ongoing = false
    FROM device_status_history h
    WHERE device_offline_periods.device_id = h.device_id
        AND device_offline_periods.is_ongoing = true
        AND h.status IN ('stale', 'offline')
        AND h.ended_at IS NOT NULL;

    -- Create new offline periods from history
    INSERT INTO device_offline_periods (device_id, offline_start, offline_end, duration_seconds, is_ongoing)
    SELECT
        device_id,
        started_at,
        ended_at,
        duration_seconds,
        ended_at IS NULL
    FROM device_status_history
    WHERE status IN ('stale', 'offline')
        AND NOT EXISTS (
            SELECT 1 FROM device_offline_periods
            WHERE device_offline_periods.device_id = device_status_history.device_id
                AND device_offline_periods.offline_start = device_status_history.started_at
        );
END;
$$ LANGUAGE plpgsql;
```

---

## Phase 3: Client-Side Simplification

### 3.1 Mobile App Changes

**Remove from app:**
- `_deviceOnlineStatus` getter - DELETE
- Gap detection logic (lines 404-485) - DELETE
- Offline period calculation - DELETE
- All threshold constants (65s, etc.) - DELETE

**Replace with:**
```dart
// Just read from database
final device = await _supabase
    .from('moveometers')
    .select('connection_status, seconds_since_last_data, connection_quality_score')
    .eq('device_id', deviceId)
    .single();

// Display the status
final status = device['connection_status']; // 'online', 'stale', 'offline'
final secondsAgo = device['seconds_since_last_data'];
final quality = device['connection_quality_score'];
```

**For offline periods in charts:**
```dart
// Query pre-computed offline periods
final offlinePeriods = await _supabase
    .from('device_offline_periods')
    .select('offline_start, offline_end')
    .eq('device_id', deviceId)
    .gte('offline_start', oneHourAgo.toIso8601String())
    .order('offline_start');

// Just display them - no calculation needed
```

### 3.2 Web Dashboard Changes

**Remove from dashboard.js:**
- `checkDeviceOnlineStatus()` function - DELETE
- All threshold constants - DELETE
- Gap detection in charts - DELETE
- Device status calculation (lines 1580-1609) - DELETE

**Replace with:**
```javascript
// Just read from database
const { data: device } = await db
    .from('moveometers')
    .select('connection_status, seconds_since_last_data, connection_quality_score')
    .eq('device_id', deviceId)
    .single();

// Update UI
updateStatusDisplay(device.connection_status, device.seconds_since_last_data);
```

---

## Phase 4: Migration Steps

### Step 1: Database Setup
1. Run schema migrations (add columns, create tables)
2. Create functions and triggers
3. Set up scheduled job for stale device checking
4. Backfill initial status for existing devices

### Step 2: Test Server-Side Logic
1. Insert test data and verify status updates correctly
2. Check that status history is being recorded
3. Verify scheduled job runs and updates stale devices
4. Validate offline periods are computed correctly

### Step 3: Update Clients (Mobile App)
1. Remove all status calculation logic
2. Update queries to read status from database
3. Remove gap detection and offline period calculation
4. Test thoroughly
5. Deploy

### Step 4: Update Clients (Web Dashboard)
1. Remove all status calculation logic
2. Update to read from database
3. Remove chart gap detection
4. Test thoroughly
5. Deploy

### Step 5: Cleanup
1. Remove unused functions from client code
2. Remove unused constants and thresholds
3. Update documentation
4. Monitor for issues

---

## Success Criteria

✅ Device status (online/stale/offline) is calculated server-side
✅ Status updates within 30 seconds of data changes
✅ Status history is recorded for analytics
✅ Offline periods are pre-computed
✅ Mobile app contains ZERO status calculation logic
✅ Web dashboard contains ZERO status calculation logic
✅ Clients only read and display database values
✅ Consistent status shown across web and mobile
✅ No timestamp comparison on client side
✅ No threshold constants in client code

---

## Benefits

1. **Single Source of Truth** - Status calculated once, in one place
2. **Consistency** - Web and mobile always show same status
3. **Performance** - Clients don't do calculations
4. **Maintainability** - Change thresholds in one place
5. **Scalability** - Server-side logic scales better
6. **Reliability** - Database triggers ensure accurate status
7. **Debuggability** - Status history table for troubleshooting
8. **Simplicity** - Clients become dumb displays

---

## Timeline

- Phase 1 (Device Status): 2-3 hours
- Phase 2 (Offline Periods): 1-2 hours
- Phase 3 (Client Updates): 2-3 hours
- Phase 4 (Testing & Deploy): 1-2 hours

**Total: ~8-10 hours of work**

---

## Next Steps

1. Review and approve this plan
2. Create database migration scripts
3. Implement and test server-side functions
4. Update clients to use new architecture
5. Deploy and monitor

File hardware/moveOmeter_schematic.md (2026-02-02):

# moveOmeter Hardware Schematic
**ESP32-C6 Feather + mmWave SEN0623 Fall Detection Sensor**

## 🔌 Circuit Diagram

```
┌──────────────────────────────────────────────────────────────────────┐
│                      ESP32-C6 FEATHER                                │
│                                                                      │
│  USB-C ───────┬──── Power Input (5V)                                │
│               │                                                      │
│               ├──── 5V Rail ────────────┐                           │
│               │                          │                           │
│               └──── 3.3V Regulator      │                           │
│                          │               │                           │
│                          │               │                           │
│  ┌───────────────────────┼───────────────┼─────────────────────┐   │
│  │                       │               │                     │   │
│  │  GPIO16 (TX1) ────────┼───────────────┼─────────────┐       │   │
│  │  GPIO17 (RX1) ────────┼───────────────┼──────┐      │       │   │
│  │  GPIO5  (PWR) ────────┼───────────────┼────┐ │      │       │   │
│  │                       │               │    │ │      │       │   │
│  │  GND ─────────────────┼───────────────┼──┐ │ │      │       │   │
│  │                       │               │  │ │ │      │       │   │
│  └───────────────────────┼───────────────┼──┼─┼─┼──────┼───────┘   │
│                          │               │  │ │ │      │           │
└──────────────────────────┼───────────────┼──┼─┼─┼──────┼───────────┘
                           │               │  │ │ │      │
                           │               │  │ │ │      │
                       3.3V│           5V ─┘  │ │ │      │
                           │               │  │ │ │      │
                           │               │  │ │ │      │
                           │    ┌──────────┴──┘ │ │      │
                           │    │  MOSFET       │ │      │
                           │    │  (2N7002)     │ │      │
                           │    │               │ │      │
                           │    │   D (Drain)   │ │      │
                           │    │    │          │ │      │
                GPIO5 ─────┼────┤ G (Gate)      │ │      │
                (PWR)      │    │    │          │ │      │
                           │    │   S (Source)  │ │      │
                           │    └────┼──────────┘ │      │
                           │         │GND         │      │
                           │         │            │      │
                           │         │            │      │
        ┌──────────────────┴─────────┴────────────┴──────┴──────┐
        │                                                         │
        │           DF ROBOT SEN0623 mmWAVE SENSOR              │
        │                   (C1001)                              │
        │                                                         │
        │  VCC (5V) ◄───── From MOSFET Drain (Switched 5V)      │
        │  GND      ◄───── GND                                   │
        │  TX       ◄───── GPIO17 (ESP32 RX1)                    │
        │  RX       ◄───── GPIO16 (ESP32 TX1)                    │
        │                                                         │
        └─────────────────────────────────────────────────────────┘
```

---

## 📋 Pin Connections

### ESP32-C6 Feather → mmWave Sensor

| ESP32-C6 Pin | Function | → | mmWave Pin | Wire Color Suggestion |
|---|---|---|---|---|
| GPIO16 | UART TX | → | RX | Yellow |
| GPIO17 | UART RX | → | TX | Orange |
| 5V (via MOSFET) | Power | → | VCC | Red |
| GND | Ground | → | GND | Black |
| GPIO5 | Power Control | → | MOSFET Gate | Blue |

---

## 🔧 Power Control Circuit (Detailed)

### Component: N-Channel MOSFET (2N7002 or similar)

```
                     +5V (from ESP32)
                       │
                       │
                    ┌──┴──┐
                    │     │
                    │  D  │ ← Drain (to sensor VCC)
                    │     │
         GPIO5 ──┬──┤  G  │ ← Gate (control signal)
                 │  │     │
                 │  │  S  │ ← Source (to GND)
                 │  │     │
                 │  └──┬──┘
                 │     │
                 │    GND
                 │
              10kΩ pull-down
                 │
                GND

```

### Why MOSFET Power Control?

**Problem:** mmWave sensor occasionally needs reset but ESP32 doesn't
**Solution:** ESP32 can power cycle just the sensor via GPIO

**Benefits:**
- Sensor reset without full system reboot
- Can implement automatic recovery
- ESP32 stays connected to WiFi
- Can reset sensor on schedule or error detection

---

## 🛠️ Parts List

| Qty | Component | Part Number | Cost | Source | Notes |
|-----|---|---|---|---|---|
| 1 | ESP32-C6 Feather | Adafruit ESP32-C6 | $15 | Adafruit | Main controller |
| 1 | mmWave Sensor | DF Robot SEN0623 | $30 | DFRobot | Fall detection |
| 1 | N-Channel MOSFET | 2N7002 or AO3400 | $0.50 | DigiKey | Power switch |
| 1 | Resistor 10kΩ | 1/4W | $0.10 | DigiKey | Pull-down |
| 4 | Jumper Wires | 22 AWG | $2 | Amazon | Connections |
| 1 | USB-C Cable | 6ft | $5 | Amazon | Power |
| 1 | Enclosure | 4"x3"x2" | $8 | Amazon | Optional |
| | | | **~$61** | | |

---

## 🔌 Power Specifications

### Power Budget

| Component | Voltage | Current | Power |
|---|---|---|---|
| ESP32-C6 (active) | 3.3V | ~80mA | 0.26W |
| ESP32-C6 (WiFi TX) | 3.3V | ~200mA | 0.66W |
| mmWave Sensor | 5V | ~150mA | 0.75W |
| **Total** | | **~430mA** | **~1.7W** |

### Power Supply Options

1. **USB Power (Recommended)**
   - USB-C port on ESP32-C6
   - 5V @ 2A capable
   - Always-on deployment

2. **Battery Power** (Future)
   - LiPo 3.7V 2000mAh
   - ~4-6 hours runtime
   - Add deep sleep: 24+ hours

3. **Wall Adapter**
   - 5V @ 2A USB adapter
   - Clean, regulated power
   - Best for permanent installation

---

## 💻 Software - Power Control Functions

Add these to your Arduino code:

```cpp
// Pin definitions
#define SENSOR_POWER_PIN 5  // GPIO5 controls MOSFET

void setup() {
  // Configure sensor power control pin
  pinMode(SENSOR_POWER_PIN, OUTPUT);
  digitalWrite(SENSOR_POWER_PIN, HIGH);  // Sensor ON by default

  // Rest of setup...
}

// Function to reset sensor
void resetSensor() {
  USB_SERIAL.println("Resetting mmWave sensor...");

  // Power off sensor
  digitalWrite(SENSOR_POWER_PIN, LOW);
  delay(2000);  // Wait 2 seconds

  // Power on sensor
  digitalWrite(SENSOR_POWER_PIN, HIGH);
  delay(10000);  // Wait 10 seconds for sensor init

  // Reconfigure sensor
  sensor.configWorkMode(DFRobot_HumanDetection::eFallingMode);
  sensor.dmInstallHeight(250);

  USB_SERIAL.println("Sensor reset complete!");
}

// Optional: Auto-reset if sensor stops responding
void checkSensorHealth() {
  static int unchangedCount = 0;
  static uint16_t lastTrackX = 0;
  static uint16_t lastTrackY = 0;

  uint16_t trackX = sensor.dmHumanData(DFRobot_HumanDetection::track_x);
  uint16_t trackY = sensor.dmHumanData(DFRobot_HumanDetection::track_y);

  // If position hasn't changed in 20 readings (100 seconds)
  if (trackX == lastTrackX && trackY == lastTrackY) {
    unchangedCount++;
    if (unchangedCount > 20) {
      USB_SERIAL.println("WARNING: Sensor appears frozen!");
      resetSensor();
      unchangedCount = 0;
    }
  } else {
    unchangedCount = 0;
  }

  lastTrackX = trackX;
  lastTrackY = trackY;
}
```

---

## 🔧 Assembly Instructions

### Step 1: Solder Headers (if needed)
- ESP32-C6 Feather usually comes with headers pre-soldered
- If not, solder male headers to ESP32-C6

### Step 2: Wire MOSFET Power Switch
1. **MOSFET Drain** → **5V rail** (red wire)
2. **MOSFET Gate** → **GPIO5** (blue wire) + 10kΩ pull-down resistor to GND
3. **MOSFET Source** → **GND** (black wire)
4. **MOSFET Drain** → **Sensor VCC** (red wire)

### Step 3: Wire UART Communication
1. **ESP32 GPIO16** → **Sensor RX** (yellow wire)
2. **ESP32 GPIO17** → **Sensor TX** (orange wire)

### Step 4: Wire Ground
1. **ESP32 GND** → **Sensor GND** (black wire)

### Step 5: Mount in Enclosure (Optional)
1. Drill holes for USB-C cable
2. Mount ESP32 with standoffs or double-sided tape
3. Mount sensor facing outward
4. Label: "moveOmeter - Fall Detection"

---

## 📐 Physical Layout

```
┌─────────────────────────────────────┐
│  ENCLOSURE (4" x 3" x 2")           │
│                                      │
│  ┌──────────────┐                   │
│  │              │  ◄─ USB-C cable   │
│  │  ESP32-C6    │═══════════════════╗
│  │  Feather     │                   ║
│  │              │                   ║
│  └───┬──────┬───┘                   ║
│      │      │                       ║
│   ┌──┴──────┴──┐                    ║
│   │  MOSFET    │                    ║
│   │  Circuit   │                    ║
│   └──┬─────────┘                    ║
│      │                              ║
│  ┌───┴──────────────┐               ║
│  │                  │               ║
│  │  mmWave Sensor   │ ◄── Faces out║
│  │  (SEN0623)       │               ║
│  │                  │               ║
│  │  [  Sensor  ]    │               ║
│  │  [  Area    ]    │               ║
│  │                  │               ║
│  └──────────────────┘               ║
│                                     ║
└─────────────────────────────────────╝

Side View:
     ║
     ║ Power
     ║
┌────╨─────┐
│  ESP32   │
├──────────┤
│ MOSFET   │
├──────────┤
│          │
│  Sensor  │ ──► Sensing direction
│          │
└──────────┘
```

---

## 🧪 Testing Procedure

### 1. Initial Power-On Test
- [ ] Plug in USB-C cable
- [ ] ESP32 blue LED lights up
- [ ] Serial Monitor shows "Sensor ready!"

### 2. Sensor Detection Test
- [ ] Stand in front of sensor (3-10 feet away)
- [ ] `human_existence` should show `1`
- [ ] Walk around - `track_x` and `track_y` should change

### 3. Power Control Test
- [ ] Upload code with `resetSensor()` function
- [ ] Call `resetSensor()` from Serial Monitor or button
- [ ] Sensor should power off → wait → power on → reinit

### 4. Long-Term Stability Test
- [ ] Run for 24 hours
- [ ] Monitor for frozen sensor values
- [ ] Check if auto-reset triggers

---

## 🔐 Safety Notes

⚠️ **IMPORTANT:**
- Use only 5V power supply (not 12V!)
- MOSFET rating: min 20V, 200mA
- Don't short VCC to GND
- Sensor draws ~150mA - ensure USB supply can handle it
- Mount sensor securely - it's sensitive to vibration

---

## 📊 Pinout Reference

### ESP32-C6 Feather Pinout
```
        USB-C
          ║
    ┌─────╨─────┐
    │           │
5V  │●         ●│ GND
GND │●         ●│ 3V
16  │●  ESP32 ●│ A0
17  │●   C6   ●│ A1
5   │●  Feather●│ A2
6   │●         ●│ SCK
    │●         ●│ MISO
    │●         ●│ MOSI
    │           │
    └───────────┘
```

### SEN0623 Sensor Pinout
```
    ┌───────────┐
    │  Sensor   │
    │  [||||]   │ ← Radar antenna
    │           │
    │  ○ VCC    │ (5V)
    │  ○ GND    │ (Ground)
    │  ○ TX     │ (Data out to ESP32 RX)
    │  ○ RX     │ (Data in from ESP32 TX)
    │           │
    └───────────┘
```

---

## 🚀 Next Steps

1. **Order Parts** (~$61 total, 2-5 day shipping)
2. **Assemble Circuit** (30 minutes)
3. **Upload Code with Power Control** (5 minutes)
4. **Test Sensor Reset** (10 minutes)
5. **Deploy** in target location

---

## 📁 File Locations

- **This Schematic:** `hardware/moveOmeter_schematic.md`
- **Firmware:** `pictureFrame/software/mmWave_Supabase_collector/`
- **Database:** `database/`
- **Web Dashboard:** `web/dashboard/`

---

**Need help building this?** Let me know and I can create more detailed assembly photos or video instructions!

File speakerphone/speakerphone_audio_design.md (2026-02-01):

# Elderly Speakerphone Audio Design Guide
## Achieving Loud, Clear, Full-Duplex Voice Communication

---

## The Core Challenge

Building a speakerphone is **much harder** than building a speaker OR a microphone system. The fundamental problem:

```
┌─────────────────────────────────────────────────────────────┐
│  THE ECHO PROBLEM                                           │
│                                                             │
│  Remote Caller's Voice ──→ [Speaker] ──→ Room ──→ [Mic] ───┐
│                                                             │
│  Without AEC, the remote caller hears their own voice      │
│  delayed by ~50-200ms = UNUSABLE                           │
└─────────────────────────────────────────────────────────────┘
```

Professional speakerphones (Polycom, Jabra) spend **80% of their engineering** on audio processing. Here's how to do it right.

---

## Architecture Overview

### Recommended System Architecture

```
┌─────────────────────────────────────────────────────────────────────────┐
│                        AUDIO SUBSYSTEM                                  │
│                                                                         │
│  ┌─────────────┐     ┌─────────────────────────────────────────────┐   │
│  │ MEMS Mics   │────→│           ESP32-S3                          │   │
│  │ (2x array)  │ I2S │  ┌─────────────────────────────────────┐    │   │
│  └─────────────┘     │  │  ESP-SR Audio Front End (AFE)       │    │   │
│                      │  │  ┌─────┐ ┌────┐ ┌────┐ ┌─────┐     │    │   │
│  ┌─────────────┐     │  │  │ AEC │→│ NS │→│AGC │→│ VAD │     │    │   │
│  │Echo Ref Sig │────→│  │  └─────┘ └────┘ └────┘ └─────┘     │    │   │
│  │(from amp)   │ ADC │  └─────────────────────────────────────┘    │   │
│  └─────────────┘     │                    │                        │   │
│                      │                    ▼                        │   │
│                      │           Clean voice to LTE modem          │   │
│                      │                                             │   │
│                      │  ┌─────────────────────────────────────┐    │   │
│                      │  │  Audio from LTE Modem (far-end)     │    │   │
│                      │  └───────────────┬─────────────────────┘    │   │
│                      │                  │                          │   │
│                      └──────────────────┼──────────────────────────┘   │
│                                         │ I2S                          │
│                                         ▼                              │
│  ┌──────────────────────────────────────────────────────────────────┐  │
│  │              CLASS D AMPLIFIER (5-10W)                           │  │
│  │   ┌────────────┐    ┌────────────┐    ┌────────────────────┐    │  │
│  │   │ I2S Input  │───→│ DAC + Amp  │───→│ Speaker Driver     │    │  │
│  │   └────────────┘    └────────────┘    └────────────────────┘    │  │
│  │                                              │                   │  │
│  │                     Echo Reference ──────────┘                   │  │
│  └──────────────────────────────────────────────────────────────────┘  │
│                                         │                              │
│                                         ▼                              │
│  ┌──────────────────────────────────────────────────────────────────┐  │
│  │              SPEAKER SYSTEM                                      │  │
│  │   ┌────────────────────────────────────────────────────────┐    │  │
│  │   │  3" Full-Range Driver + Tuned Wood Enclosure           │    │  │
│  │   │  Target: 90+ dB SPL @ 1m, 150Hz - 15kHz               │    │  │
│  │   └────────────────────────────────────────────────────────┘    │  │
│  └──────────────────────────────────────────────────────────────────┘  │
└─────────────────────────────────────────────────────────────────────────┘
```

---

## Part 1: Microphone System

### Why Two Microphones?

Two microphones enable:
1. **Beamforming** - Focus on voices from a specific direction
2. **Noise reduction** - Better separation of voice from background noise
3. **Improved AEC** - More robust echo cancellation

### Recommended Microphones

| Microphone | Interface | SNR | Sensitivity | Price | Notes |
|---|---|-----|---|---|---|
| **INMP441** | I2S | 61dB | -26dBFS | ~$2 | Most common, good value |
| **SPH0645LM4H** | I2S | 65dB | -26dBFS | ~$4 | Higher SNR, Adafruit uses |
| **ICS-43434** | I2S | 65dB | -26dBFS | ~$3 | TDK, very good performance |
| **MSM261S4030H0R** | I2S | 64dB | -26dBFS | ~$2 | Used in ESP32-S3-BOX |

**Recommendation:** Use **2x INMP441** or **2x SPH0645** in an array configuration.

### Microphone Placement

```
┌─────────────────────────────────────────┐
│                                         │
│     [MIC 1]─────40-60mm─────[MIC 2]     │  ← Horizontal array
│                                         │
│              ┌─────────┐                │
│              │ SPEAKER │                │
│              │   ███   │                │
│              └─────────┘                │
│                                         │
│         [  BIG BUTTON  ]                │
│                                         │
└─────────────────────────────────────────┘
         ↑
    User faces this direction
```

**Critical placement rules:**
- Mic spacing: **40-80mm** (ESP-SR requirement)
- Place mics **away from speaker** (reduce direct acoustic coupling)
- Orient mics to face the user
- Avoid placing mics near vibration sources

### Microphone Circuit

```
                    3.3V
                      │
                      ├───[10µF]───┐
                      │            │
                 ┌────┴────┐       │
                 │ INMP441 │       │
                 │         │       │
    BCLK ───────→│ SCK     │       │
    WS ─────────→│ WS      │       │
    DATA ←───────│ SD      │       │
                 │ L/R     │───────┤ (GND=Left, VDD=Right)
                 │ GND     │───────┴───GND
                 └─────────┘

    Wire both mics to same I2S bus, one as Left, one as Right channel
```

---

## Part 2: Echo Cancellation (The Hard Part)

### How AEC Works

```
┌─────────────────────────────────────────────────────────────────┐
│                    AEC BLOCK DIAGRAM                            │
│                                                                 │
│   Far-End Audio ──┬──────────────────────────────→ Speaker     │
│   (from caller)   │                                             │
│                   │                                             │
│                   ▼                                             │
│            ┌─────────────┐                                      │
│            │  Adaptive   │ ← Learns room acoustics              │
│            │   Filter    │                                      │
│            └──────┬──────┘                                      │
│                   │ Estimated Echo                              │
│                   ▼                                             │
│   Mic Input ──→ [  -  ] ──→ Cleaned Voice ──→ To Caller        │
│   (voice+echo)   Subtract                                       │
│                                                                 │
└─────────────────────────────────────────────────────────────────┘
```

### ESP32-S3 + ESP-SR: Built-in AEC

The ESP32-S3 with ESP-SR (Speech Recognition) framework includes:

| Algorithm | Function |
|---|---|
| **AEC** | Acoustic Echo Cancellation - removes speaker output from mic input |
| **NS** | Noise Suppression - removes background noise |
| **AGC** | Automatic Gain Control - normalizes volume levels |
| **VAD** | Voice Activity Detection - knows when someone is speaking |
| **BSS** | Blind Source Separation - beamforming with mic array |

**Resource usage on ESP32-S3:**
- CPU: ~22%
- SRAM: ~48KB
- PSRAM: ~1.1MB

### Echo Reference Signal (CRITICAL!)

For AEC to work, the DSP needs to know exactly what audio is being sent to the speaker. This is called the **echo reference signal**.

**Method 1: Digital Loopback (Recommended)**
```
ESP32-S3 I2S TX ──┬──→ Amplifier ──→ Speaker
                  │
                  └──→ AFE Reference Input (digital copy)
```

**Method 2: Analog Tap from Amplifier Output**
```
Amplifier Output ──┬──→ Speaker
                   │
                   └──→ [Voltage Divider] ──→ [LPF 22kHz] ──→ ADC ──→ AFE Reference
```

ESP-SR input format example: `"MMNR"` = Mic1, Mic2, Null, Reference

### AEC Tuning Guidelines (from Espressif)

| Parameter | Requirement |
|---|---|
| Reference signal delay | 0-10ms relative to mic signal |
| Speaker THD at max volume | <10% @ 100Hz, <6% @ 200Hz, <3% @ 350Hz+ |
| Mic signal at max volume | Must not clip/saturate |
| Reference voltage | Must not exceed ADC max input |

---

## Part 3: Amplifier Selection

### Why 3W Isn't Enough

The MAX98357A (3W) is popular but **not loud enough** for hard-of-hearing elderly:

| Amplifier Power | SPL with 87dB/W Speaker | Notes |
|---|---|---|
| 1W | 87 dB | Quiet conversation |
| 3W | 92 dB | Normal TV volume |
| 5W | 94 dB | Loud, but achievable |
| 10W | 97 dB | Very loud, target for elderly |

**Target: 90-95 dB SPL at 1 meter** (equivalent to 40dB amplification from the search results)

### Amplifier Options

#### Option 1: MAX98357A (Simple, 3W)
- **Pros:** I2S input, simple, cheap (~$5), no external components
- **Cons:** Only 3W, may not be loud enough
- **Use if:** Testing/prototyping, or with very efficient speaker

#### Option 2: MAX98390 (I2S, 10W, with DSP)
- **Specs:** 10W into 4Ω, I2S input, built-in DSP
- **Pros:** More power, integrated speaker protection, I2S
- **Cons:** More expensive (~$15), harder to source
- **Best for:** Production design

#### Option 3: TAS5805M (I2S, 23W)
- **Specs:** 23W mono, I2S input, built-in DSP/EQ
- **Pros:** Very powerful, programmable DSP
- **Cons:** Needs 12-26V supply, more complex
- **Best for:** High-end design

#### Option 4: TPA3116D2 + External DAC (Analog, 50W+)
- **Specs:** 50-100W depending on supply voltage
- **Pros:** Very loud, cheap (~$5), widely available
- **Cons:** Needs separate DAC (PCM5102), higher voltage supply
- **Best for:** Maximum volume

### Recommended: TAS5805M or MAX98390

For a **premium elderly speakerphone**, I recommend:

```
┌─────────────────────────────────────────────────────────────┐
│  TAS5805M Configuration                                     │
│                                                             │
│  ESP32-S3 ──[I2S]──→ TAS5805M ──→ 10W Speaker              │
│             BCLK                                            │
│             LRCLK        12V Supply                         │
│             DIN          │                                  │
│                          ▼                                  │
│                    ┌──────────┐                             │
│                    │ TAS5805M │                             │
│                    │          │──→ OUTP ──┐                 │
│                    │          │           │ BTL Output      │
│                    │          │──→ OUTN ──┴──→ Speaker      │
│                    └──────────┘                             │
│                                                             │
│  Features:                                                  │
│  - Built-in EQ (boost voice frequencies 1-4kHz)            │
│  - Limiter (prevent clipping at max volume)                │
│  - Thermal protection                                       │
│  - I2C control for volume                                   │
└─────────────────────────────────────────────────────────────┘
```

---

## Part 4: Speaker Selection

### Speaker Requirements for Elderly

| Parameter | Target | Why |
|---|---|-----|
| Sensitivity | 87+ dB/W/m | Louder with less power |
| Frequency Response | 150Hz - 12kHz | Voice intelligibility |
| Size | 3" (76mm) | Balance of bass and size |
| Impedance | 4Ω or 8Ω | Common, efficient |
| Power Handling | 5-10W | Match amplifier |

### Recommended Speakers

#### Budget (~$5-10):
- **Visaton FR 7** - 2.5", 8Ω, 88dB, excellent voice clarity
- **Dayton Audio CE65W-8** - 2.5", 8Ω, 82dB, good bass

#### Mid-range (~$15-25):
- **Dayton Audio ND65-8** - 2.5", 8Ω, 83.7dB, reference quality
- **Tang Band W3-881SJ** - 3", 8Ω, 86dB, excellent full-range

#### Premium (~$30-50):
- **Fountek FR89EX** - 3", 8Ω, 87dB, audiophile quality
- **Markaudio Alpair 5** - 3", 8Ω, 85dB, exceptional clarity

**Recommendation:** **Visaton FR 7** or **Tang Band W3-881SJ** - both excellent for voice.

### Enclosure Design

A proper enclosure is **critical** for loud, clear audio. The wood enclosure you mentioned is excellent!

```
┌─────────────────────────────────────────────────────────────┐
│  SEALED ENCLOSURE (Recommended for simplicity)              │
│                                                             │
│    ┌───────────────────────────────────────────┐            │
│    │                                           │            │
│    │     ████████████████████████             │ ← Speaker   │
│    │     ████████████████████████             │    driver   │
│    │                                           │            │
│    │        ┌─────────────────┐               │            │
│    │        │  Damping        │               │            │
│    │        │  Material       │               │ ← Polyester │
│    │        │  (polyfill)     │               │    fill     │
│    │        └─────────────────┘               │            │
│    │                                           │            │
│    └───────────────────────────────────────────┘            │
│                                                             │
│  Internal volume: ~0.5-1 liter for 3" driver                │
│  Material: 12-18mm MDF or hardwood                          │
│  Seal all joints with wood glue                             │
│                                                             │
└─────────────────────────────────────────────────────────────┘
```

**Enclosure calculations for 3" driver:**
- Sealed box volume: ~0.5-1.0 liters (30-60 cubic inches)
- Q factor: Target Qtc = 0.707 for flat response
- Use free software like WinISD to calculate exact volume

#### Passive Radiator Option (Better Bass)
```
┌─────────────────────────────────────────┐
│   [Speaker] ────────────────────────    │
│                                         │
│        [Passive Radiator] ───────────   │ ← Tuned for bass extension
│                                         │
└─────────────────────────────────────────┘
```

A passive radiator extends bass response without a port (which can cause noise).

---

## Part 5: Complete Bill of Materials

### Core Audio Components

| Component | Part Number | Purpose | Price | Source |
|---|---|---|---|---|
| MCU | ESP32-S3-WROOM-1 (8MB PSRAM) | Main processor + AEC | ~$4 | LCSC, Mouser |
| Mic 1 | INMP441 module | Voice input | ~$2 | Amazon, AliExpress |
| Mic 2 | INMP441 module | Voice input (array) | ~$2 | Amazon, AliExpress |
| Amplifier | TAS5805M module | 10W Class D | ~$12 | Amazon, AliExpress |
| Speaker | Tang Band W3-881SJ | 3" full-range | ~$20 | Parts Express |
| Audio Codec | ES8311 (optional) | ADC for echo ref | ~$3 | AliExpress |

### Alternative (Simpler, Less Loud)

| Component | Part Number | Purpose | Price |
|---|---|---|---|
| MCU | ESP32-S3-WROOM-1 | Main processor | ~$4 |
| Mic x2 | INMP441 | Voice input | ~$4 |
| Amplifier | MAX98357A | 3W I2S amp | ~$5 |
| Speaker | Visaton FR 7 | 2.5" full-range | ~$8 |

### Development Kit Option

If you want to skip the audio design initially:

**ESP32-S3-Korvo-2** (~$50)
- ESP32-S3 with 8MB PSRAM
- 2-mic array with ES7210 ADC
- ES8311 DAC + speaker amp
- **AEC reference signal already routed**
- Ready for ESP-ADF development

---

## Part 6: Software Architecture

### ESP-ADF Pipeline for Speakerphone

```c
// Simplified ESP-ADF pipeline for VoIP speakerphone

// Audio input pipeline (mic → AEC → encoder → network)
[i2s_stream_reader] → [algorithm_stream(AEC+NS+AGC)] → [encoder] → [network_out]

// Audio output pipeline (network → decoder → speaker)  
[network_in] → [decoder] → [i2s_stream_writer]

// Echo reference (critical for AEC)
algorithm_stream needs reference signal from i2s_stream_writer
```

### Key ESP-SR Configuration

```c
afe_config_t afe_config = {
    .aec_init = true,           // Enable AEC
    .se_init = true,            // Enable noise suppression
    .vad_init = true,           // Enable voice activity detection
    .wakenet_init = false,      // Don't need wake word for phone
    .voice_communication_init = true,  // Optimized for voice calls
    .afe_ns_mode = NS_MODE_SSP, // Single-channel noise suppression
    .afe_ns_model_name = "nsnet2",
    .pcm_config = {
        .total_ch_num = 3,      // 2 mics + 1 reference
        .mic_num = 2,
        .ref_num = 1,
        .sample_rate = 16000,
    },
};
```

---

## Part 7: Testing and Tuning

### Echo Cancellation Test Procedure

1. **Echo Return Loss (ERL) Test**
   - Play 1kHz tone through speaker at max volume
   - Measure level at microphone
   - Target: >10dB reduction from AEC

2. **Double-Talk Test**
   - Both local and remote speaking simultaneously
   - Neither should be cut off
   - Test with various volume levels

3. **Convergence Test**
   - Start call in quiet room
   - Walk around room (changing acoustics)
   - AEC should adapt within 1-2 seconds

### Voice Quality Test

1. **Loudness Test**
   - Measure SPL at 1 meter with voice playback
   - Target: 85-95 dB SPL at max volume

2. **Frequency Response**
   - Verify 300Hz-3.4kHz telephone bandwidth
   - Check for excessive bass or treble

3. **Intelligibility Test**
   - Read standardized word lists
   - Have elderly users rate clarity

---

## Part 8: Design Tips for Elderly Users

### Audio Quality Tips

1. **Boost mid-frequencies (1-4kHz)** - Voice intelligibility
2. **Reduce low frequencies (<200Hz)** - Less rumble/muddiness
3. **Add slight compression** - Keeps quiet voices audible
4. **Limit maximum volume** - Prevent hearing damage

### DSP Settings (TAS5805M EQ example)

```
Frequency Response Target:
         +6dB ──────────────────────────
              │         ┌──┐
              │        ╱    ╲
         0dB  ├───────╱      ╲──────────
              │      ╱        ╲
              │     ╱          ╲
        -6dB  ├────╱            ╲────────
              │
              └────────────────────────────
              100   500  1k  2k  4k  8k  Hz
              
              ↑         ↑↑↑
           Cut bass   Boost voice frequencies
```

### Physical Design

1. **Speaker facing UP or toward user** - Direct sound path
2. **Mics on front face** - Facing user
3. **Non-slip base** - Stays in place
4. **Visual feedback** - LED shows call status
5. **LOUD ringer** - Target 85+ dB for alerts

---

## Summary: Recommended Design

### Hardware Stack

```
┌────────────────────────────────────────────────────────────┐
│  SPEAKERPHONE BLOCK DIAGRAM                                │
│                                                            │
│  ┌──────────────┐                                          │
│  │   2x MEMS    │──I2S──┐                                  │
│  │   INMP441    │       │                                  │
│  └──────────────┘       │                                  │
│                         ▼                                  │
│  ┌──────────────┐   ┌──────────────┐   ┌──────────────┐   │
│  │   ES8311     │──→│  ESP32-S3    │──→│   A7670G     │   │
│  │ (echo ADC)   │   │  (AFE+App)   │   │  (LTE/Voice) │   │
│  └──────────────┘   └──────────────┘   └──────────────┘   │
│        ↑                   │                               │
│        │                   │ I2S                           │
│        │                   ▼                               │
│  ┌─────┴────────────────────────────────────────────────┐ │
│  │              TAS5805M (10W Class D)                  │ │
│  │                        │                             │ │
│  │              Echo Ref ─┘                             │ │
│  └─────────────────────────┬────────────────────────────┘ │
│                            │                               │
│                            ▼                               │
│                   ┌────────────────┐                       │
│                   │ Tang Band 3"   │                       │
│                   │ Full Range     │                       │
│                   │ in Wood Box    │                       │
│                   └────────────────┘                       │
│                                                            │
│  Total BOM: ~$50-70                                        │
│  Target Retail: $149-199                                   │
└────────────────────────────────────────────────────────────┘
```

### Development Approach

1. **Phase 1:** Start with ESP32-S3-Korvo-2 dev kit
   - Pre-designed audio with AEC
   - Focus on software/LTE integration
   
2. **Phase 2:** Custom PCB with selected components
   - Optimize speaker/enclosure
   - Add NFC, button, display
   
3. **Phase 3:** Production design
   - Wood enclosure tooling
   - FCC/UL certification

---

## References

- ESP-SR Documentation: https://docs.espressif.com/projects/esp-sr/
- ESP-ADF Examples: https://github.com/espressif/esp-adf/tree/master/examples
- TAS5805M Datasheet: TI Literature Number SLAS702
- Acoustic Echo Cancellation Theory: ITU-T G.167

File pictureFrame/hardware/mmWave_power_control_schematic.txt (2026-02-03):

===============================================
mmWave Sensor Power Control Circuit Schematic
===============================================

ESP32-C6 Feather to mmWave Sensor with MOSFET Power Control

Components Required:
- Q1: N-Channel MOSFET (2N7002, BS170, or IRLZ44N for higher current)
- R1: 10kΩ resistor (gate pull-down)
- R2: 220Ω resistor (gate current limiting)
- D1: 1N4148 or 1N5819 diode (flyback protection, optional but recommended)

Circuit Diagram:

                    +5V (USB or external power)
                     |
                     |
                     +-----[D1]----+
                     |     ^       |
                     |     |       |
                     +-------------+----------- VCC (to mmWave sensor)
                                   |
                                   |
                                   |
    ESP32-C6 GPIO5 ----[R2]----+--+
                                |  |
                                |  Gate
                               [R1]  |
                                |  | Q1 (N-Channel MOSFET)
                                |  |
                               GND  Drain
                                    |
                                    +----------- GND (to mmWave sensor)
                                    |
                                   GND (ESP32-C6 GND)

ASCII Schematic:

                    +5V
                     │
                     │
                  ┌──┤├──┐  D1 (Flyback Diode)
                  │  │   │
                  │  └───┼─────────► VCC (mmWave)
                  │      │
                  │      │
GPIO5 ─┬─[220Ω]──┤      │
       │    R2   │ Gate │
       │         │  │   │
       └─[10kΩ]──┤  │   │
           R1    │  ├───┤  Q1 (MOSFET)
                 │  │   │  Drain
                GND │   │
                    │   └─────────► GND (mmWave)
                    │
                   GND

Connection Details:

ESP32-C6 Feather:
- GPIO5 (Pin 5)  → R2 (220Ω) → MOSFET Gate
- GND            → MOSFET Source & R1 bottom
- 5V or USB      → mmWave VCC (always powered) OR via MOSFET if high-side

mmWave Sensor (SEN0623):
- VCC → Either directly to +5V (if using low-side switching shown above)
        OR through MOSFET Drain (if using high-side switching)
- GND → MOSFET Drain (low-side switching as shown)
- TX  → GPIO17 (ESP32-C6 RX)
- RX  → GPIO16 (ESP32-C6 TX)

How It Works:
1. When GPIO5 is LOW (0V):
   - MOSFET is OFF (open circuit)
   - No current flows through MOSFET
   - mmWave sensor has no ground path → Sensor OFF

2. When GPIO5 is HIGH (3.3V):
   - MOSFET is ON (closed circuit)
   - Current flows through MOSFET Drain to Source
   - mmWave sensor has complete circuit → Sensor ON

3. R1 (10kΩ) pulls gate LOW when GPIO5 is floating
4. R2 (220Ω) limits current into MOSFET gate
5. D1 protects against voltage spikes when sensor powers down

Component Selection Notes:

MOSFET Options (choose based on sensor current draw):
- 2N7002:    ~300mA max, good for low-power sensors
- BS170:     ~500mA max, general purpose
- IRLZ44N:   ~50A max, overkill but works great, logic-level gate

Gate Threshold Voltage:
- Use LOGIC-LEVEL MOSFETs (Vgs(th) < 3V)
- ESP32-C6 outputs 3.3V, so standard MOSFETs won't fully turn on
- IRLZ44N is recommended: Vgs(th) = 1-2V

Alternative High-Side Switching (if needed):
If you need to switch the VCC side instead of GND, use a P-Channel MOSFET
with a PNP transistor driver or a dedicated high-side switch IC.

PCB Layout Tips:
- Keep MOSFET close to sensor GND connection
- Use thick traces for power/ground (at least 20 mil for 500mA)
- Add a 100µF capacitor near mmWave VCC pin for stability
- Add 0.1µF ceramic bypass cap near ESP32-C6 GPIO5

Firmware Configuration:
In mmWave_Supabase_collector.ino:

    #define SENSOR_POWER_PIN 5
    #define ENABLE_POWER_CONTROL true  // Enable after circuit installed

    void setup() {
        pinMode(SENSOR_POWER_PIN, OUTPUT);
        digitalWrite(SENSOR_POWER_PIN, HIGH);  // Turn sensor ON
    }

    void resetSensor() {
        digitalWrite(SENSOR_POWER_PIN, LOW);   // Turn OFF
        delay(3000);
        digitalWrite(SENSOR_POWER_PIN, HIGH);  // Turn ON
        delay(10000);  // Wait for sensor init
    }

Safety Notes:
- Ensure MOSFET can handle sensor current (check mmWave datasheet)
- Add heatsink if MOSFET gets warm (unlikely at <500mA)
- Test with multimeter before connecting mmWave sensor
- Verify 0V at MOSFET drain when GPIO5 is LOW

Bill of Materials:
┌──────────┬─────────────────────┬──────────┬────────────────┐
│ Ref      │ Part                │ Qty      │ Notes          │
├──────────┼─────────────────────┼──────────┼────────────────┤
│ Q1       │ IRLZ44N MOSFET      │ 1        │ Logic-level    │
│ R1       │ 10kΩ resistor       │ 1        │ 1/4W           │
│ R2       │ 220Ω resistor       │ 1        │ 1/4W           │
│ D1       │ 1N5819 Schottky     │ 1        │ Optional       │
│ C1       │ 100µF electrolytic  │ 1        │ Optional       │
└──────────┴─────────────────────┴──────────┴────────────────┘

Testing Procedure:
1. Build circuit on breadboard WITHOUT mmWave connected
2. Measure voltage at MOSFET drain:
   - GPIO5 LOW → Should read ~5V (open circuit)
   - GPIO5 HIGH → Should read ~0V (closed circuit)
3. If measurements correct, connect mmWave sensor
4. Set ENABLE_POWER_CONTROL = true in firmware
5. Upload and test resetSensor() function

Troubleshooting:
- Sensor won't turn off: Check MOSFET orientation, verify logic-level type
- Sensor won't turn on: Check all connections, measure gate voltage (should be 3.3V)
- Intermittent operation: Add capacitor, check power supply capacity
- ESP32 resets when switching: Sensor inrush current too high, add 100µF cap

===============================================

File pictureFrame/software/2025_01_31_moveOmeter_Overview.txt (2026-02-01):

2025_01_31_moveOmeter_Overview.txt

Design ethos:  security, encryption, reliability, uptime, scaling up capability, logging, monitoring and health status checkins.  These are all important and worth paying extra money for.

The moveOmeter is a picture frame that sits or hangs in the home of an elderly person with the goal of extending the amount of time they can remain in home.  The moveOmeter uses mmWave technology to monitor the movements of the elderly person and reports movement live to a server called moveOmeterOnline (these are awful names, feel free to come up with new ones).  The caretakers, often the kids, will then navigate to moveOmeter.com, which I have, and there is a login button.  When they click that they can login via any standard ways with 2 factor authenticaion, passkey or the 6 digit authenticaion codes.  When they login they can see everything we are able to calculate from the sensors.  

We will call this "Analytics" for now.  Analytics can include an overall 'motion' score that we figure out, steps per day, wake up time, go to sleep time, sleep quality, exterior doors opening + closing, any sudden motions, and any other metrics we can figure out.  

The moveOmeterServer will record all live data to go back to an re-analyze as our algorithms improve.  This might add up to a lot, so when you design it take into account statistics for each of these stages: 100 customers, 1,000 customers, 10,000 customers, 1M and 5M customers.  Answer the question in your plan: how would we scale at each transition?  We want to store all raw data.  

The caretakers can also download an app onto their iphone or android device that is organized as many apps are with 3-4 icons across the bottom and profile/setup in the top right of the banner.  It shows all the same data as the website, and all the same functionality.  Any functionality spoken about on the app will occur on the website.  This is a rule, so all new designs and features include both a web layout and an app (iphone + android) layout. 

Long term analytics: weekly and month 'movement' trends, wake and sleep times.  

Locations:
- on a table, possibly with other picture frames
- on the wall
- under the bed looking up for sleep analysis

side note: this can work for elderly pets as well when humans are at work.

Hardware:
Picture Frame:
The ADAFRUIT ESP32-C6 FEATHER will be the processor in the moveOmeter, and it will receive data via uart from the mmWave DF Robot SEN0623.  Depending on how that goes we will likely also test the mmWave DF Robot SEN0610 to see if the added benefits of using both sensors are worth it.  If so then we would have the ESP32-C6 recieve data from both and send it directly to the moveOmeterServer via encrypted MQTT (feel free to change this) where it is stored and analyzed.

moveOmeter Server: 
This will be a digital ocean node, but feel free to recommend something different.  
Database will be supabase, use all of the features of supabase to make this easy and reliable.  
Serve webpages querying the supabase data.  think about caching or some kind of offline data processing and number crunching so the statistics are calculated.  Have these versioned so we can run them again with improved versions of our data   

Software:
Picture Frame:
code running on the ADAFRUIT ESP32-C6 FEATHER will parse the data coming from both mmWave devices, and also be able to send any commands to them that are listed in the user manuals for configuration and such.  all of these settings will be stored in an .ini file to be resent on power up if the mmWave devices don't have persistent memory.  
The ESP32-C6 will know what server to connect to.. do this in a way that other IOT devices do (i.e. which IP, use DNS?).  It will then establish credentials and all the data from the mmWaves gets sent to a big 'raw data' database via MQTT (or however you like) with the UnitID and SensorID.  

supabase:
receive MQTT (or whatever you like) from all the moveOmeters out in the real world, though these should all just communicate with supabase.  
do the load forecasts and cost analysis. 
Each moveOmeter out in the world has a unique ID (serial number).. this is all that it is required to know, but it will likely store all of it's identifiers and send them just for redundancy.  
- Serial number (combination of model number + counter)
- House unique ID and name (each customer can have multiple houses, each house can have multiple moveOmeters)

The database:
- table of actual moveOmeters (each entry is a moveOmeter)
-- includes unique ID, model number ID, SIM card number, UUID number, MAC Address, manufacture date, manufacture batch #,   
- table of moveOmeter models
-- includes unique ID, checkboxes for sensors and capabilities

Build the webserver however you like.

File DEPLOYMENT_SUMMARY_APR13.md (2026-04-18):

# Deployment Summary - April 13, 2026

## 🔧 Issues Fixed Today

### 1. Offline Device Display Issue ✅
**Problem:** Dashboard showed stale data from yesterday without indicating device was offline
**Solution:**
- Added red overlay on timeline graphs when device offline
- Enhanced "Last Update" field to show prominent warnings when data is old
- Shows "DEVICE OFFLINE (24h 15m ago)" on graphs
- Last Update turns red and bold for stale data

### 2. Critical Memory Leaks Fixed ✅
**Problem:** Dashboard was accumulating intervals and subscriptions, causing browser to slow down and crash
**Solution:**
- Added cleanup for all setInterval calls
- Added cleanup for realtime subscriptions
- Intervals now cleared on page unload
- Prevents resource accumulation on page refresh
- **This was likely the #1 cause of dashboard failures**

### 3. Analytics Error Handling ✅
**Problem:** If analytics.js failed to load, entire dashboard would crash
**Solution:**
- Wrapped all analytics in try-catch blocks
- Made analytics optional, not required
- Dashboard continues working even if analytics fails
- Prevents CDN failures from breaking dashboard

### 4. Database Retry Logic ✅
**Problem:** Temporary network glitches caused permanent dashboard failure
**Solution:**
- Added exponential backoff retry (3 attempts)
- Handles network timeouts gracefully
- Only fails after multiple retry attempts

### 5. Offline Detection ✅
**Problem:** Users had no indication when they lost internet connection
**Solution:**
- Added window.addEventListener('offline')
- Shows "No Internet Connection" message
- Shows "Reconnecting..." when back online
- Auto-recovers when connection restored

### 6. CDN Error Handlers ✅
**Problem:** Silent failures when CDN libraries failed to load
**Solution:**
- Added onerror handlers to all CDN script tags
- User-friendly error messages
- Clear guidance to refresh page

### 7. Missing Login Page ✅
**Problem:** login.html was missing from server
**Solution:**
- Deployed login.html
- Deployed auth.js and config.js dependencies

### 8. Public Website Broken ✅
**Problem:** Public landing page was replaced by dashboard, causing redirect loop
**Solution:**
- Restored public landing page (stillKicking) to index.html
- Moved dashboard to dashboard.html
- Updated auth flow to redirect to /dashboard.html
- Deployed to correct directory (/var/www/moveometer/)

---

## 📂 Final Directory Structure

### /var/www/moveometer/ (Production)
```
index.html              → Public landing page (stillKicking)
contact.html            → Contact page (public)
login.html              → Login page (public)
dashboard.html          → Dashboard (requires auth)
admin.html              → Admin panel (requires admin auth)
firmware.html           → Firmware updates (requires employee auth)
config.js               → Supabase configuration
auth.js                 → Authentication logic
auth-guard.js           → Auth protection (with memory leak fixes)
dashboard.js            → Dashboard logic (with all critical fixes)
analytics.js            → Analytics tracking (with error handling)
caretaker_management.js → Caretaker management features
```

---

## 🌐 URL Structure (Correct)

| URL | Page | Access |
|-----|---|---|
| moveometer.com/ | Public landing page | ✅ Public |
| moveometer.com/contact.html | Contact form | ✅ Public |
| moveometer.com/login.html | Login page | ✅ Public |
| moveometer.com/dashboard.html | Dashboard | 🔒 Auth required |
| moveometer.com/admin.html | Admin panel | 🔒 Admin only |
| moveometer.com/firmware.html | Firmware updates | 🔒 Employee only |

---

## 🔄 Authentication Flow

1. User visits **moveometer.com/** → sees public landing page
2. Clicks "Login" → goes to **moveometer.com/login.html**
3. Enters credentials → successful login
4. Redirected to **moveometer.com/dashboard.html**
5. Auth-guard checks authentication on dashboard.html
6. If not authenticated → redirects back to login.html

---

## ✅ Files Deployed (Final)

### Public Website Files:
- ✅ index.html (public landing page)
- ✅ contact.html (contact page)

### Authentication Files:
- ✅ login.html
- ✅ auth.js (updated to redirect to /dashboard.html)
- ✅ auth-guard.js (updated with memory leak fixes)
- ✅ config.js

### Dashboard Files:
- ✅ dashboard.html (renamed from index.html)
- ✅ dashboard.js (with memory leak fixes, retry logic, offline annotations)
- ✅ analytics.js (with error handling, cleanup)
- ✅ caretaker_management.js

### Admin Files:
- ✅ admin.html
- ✅ firmware.html

---

## 🧪 Testing Completed

- ✅ Public website loads at moveometer.com
- ✅ Login page accessible
- ✅ Dashboard accessible after login
- ✅ Offline device shows visual indicators
- ✅ Memory leaks fixed (verified with cleanup logs)
- ✅ Analytics optional (won't crash if fails)
- ✅ Offline detection working

---

## 📊 Critical Fixes Impact

### Before:
- Dashboard would slow down after 1-2 hours
- Random crashes when analytics failed
- No indication when device offline
- Network glitches caused permanent failures
- Public website was broken (redirect loop)

### After:
- Dashboard stable for extended periods
- Analytics failures handled gracefully
- Clear visual indication when device offline
- Network issues retry automatically
- Public website working correctly

---

## 🎯 Expected Results

### Immediate:
- ✅ Public website accessible
- ✅ Dashboard more stable
- ✅ Clear offline indicators
- ✅ Better error messages

### Within 24-48 Hours:
- Dashboard uptime should improve significantly
- "Dashboard went off" reports should decrease dramatically
- Memory usage stays stable (under 200 MB)
- Better user experience during network issues

---

## 📝 Deployment Commands Used

```bash
# Deploy public landing page
scp pictureFrame/software/landing_page/index.html root@moveometer.com:/var/www/moveometer/

# Deploy dashboard and auth files
scp web/dashboard/dashboard.html web/dashboard/auth-guard.js web/dashboard/auth.js \
    web/dashboard/dashboard.js web/dashboard/analytics.js web/dashboard/config.js \
    root@moveometer.com:/var/www/moveometer/

# Deploy login page
scp web/dashboard/login.html root@moveometer.com:/var/www/moveometer/
```

---

## 🔍 Monitoring Points

Watch for these success indicators over next 24-48 hours:

1. **Memory Usage:** Should stay under 200 MB even after hours of use
2. **Console Logs:** Should see cleanup messages on page unload
3. **No Crashes:** Dashboard should remain responsive indefinitely
4. **Offline Recovery:** Dashboard should auto-recover from brief network outages
5. **Public Website:** moveometer.com should load instantly without redirects

---

## 📚 Documentation Created

1. **AUDIT_REPORT.md** - Full analysis of 14 issues found
2. **CRITICAL_FIXES.md** - Implementation guide for all fixes
3. **FIXES_DEPLOYED.md** - Testing checklist and monitoring
4. **DEPLOYMENT_SUMMARY_APR13.md** - This summary

---

## ✅ Status: All Issues Resolved

- 🟢 Public website working
- 🟢 Dashboard accessible via login
- 🟢 Memory leaks fixed
- 🟢 Offline detection working
- 🟢 Error handling improved
- 🟢 Authentication flow correct

**Deployment Status:** COMPLETE ✅
**Last Updated:** April 13, 2026
**Deployed By:** Claude Code

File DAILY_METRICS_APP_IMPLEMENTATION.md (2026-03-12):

# Daily Metrics Mobile App Implementation

## Overview

Updated the Flutter mobile app to display daily metrics from the new `daily_aggregates` database table.

## Changes Made

### 1. Database Setup

Added two new metric columns to the `daily_aggregates` table:
- **offline_minutes**: Minutes during the day with no data
- **peak_activity_hour**: Hour (0-23) with the most movement activity

Run these SQL commands to add the columns:
```sql
-- File: database/add_new_metrics_columns.sql
ALTER TABLE daily_aggregates
  ADD COLUMN IF NOT EXISTS offline_minutes INTEGER,
  ADD COLUMN IF NOT EXISTS peak_activity_hour INTEGER CHECK (peak_activity_hour >= 0 AND peak_activity_hour <= 23);
```

### 2. Flutter Service Updates

**File: `lib/services/sensor_data_service.dart`**

Added new `DailyMetrics` model class to represent daily aggregate data:
- Date, motion score, wake/sleep times
- Active minutes, movement sessions
- Offline time, peak activity hour
- Fall count, data coverage percentage

Added three new service methods:
- `fetchDailyMetrics(deviceId, days: 7)` - Fetch past N days of metrics
- `fetchTodayMetrics(deviceId)` - Fetch today's metrics (may be incomplete)
- `fetch24HourData(deviceId, date)` - Fetch full 24-hour timeline for a specific date

### 3. New Page: Day Detail View

**File: `lib/pages/day_detail_page.dart`**

New page that shows:
- **Daily Metrics Card**: Motion score, wake/sleep times, activity stats, falls, data coverage
- **24-Hour Activity Graph**: Full day timeline with presence and movement data

The page adapts for "today" vs past days, showing "IN PROGRESS" badge for today's metrics.

### 4. Updated Device Detail Page

**File: `lib/pages/device_detail_page.dart`**

Restructured page layout (top to bottom):

1. **Last Hour Section** (existing) - Real-time data, online/offline status
2. **Today's Activity Section** (NEW) - Current day metrics so far:
   - Large motion score display
   - Quick stats tiles (active minutes, sessions, wake/last motion)
   - "IN PROGRESS" badge
3. **Past 7 Days Section** (NEW) - List of last 7 days:
   - Each day is a clickable card
   - Shows motion score badge and quick stats
   - Taps navigate to Day Detail Page for 24-hour view
4. **Daily History Section** (existing, hidden) - Old hourly bar charts

## User Experience Flow

1. User opens moveometer page → sees real-time hourly data at top
2. Scrolls down → sees today's metrics updating throughout the day
3. Scrolls down → sees past 7 days as a list
4. Taps any day → navigates to detailed view with 24-hour graph and full metrics
5. Can swipe back to return to main page

## Motion Score Color Coding

- **Green (70-100)**: Very Active
- **Orange (40-69)**: Moderate Activity
- **Red (0-39)**: Low Activity

## Next Steps

### To Deploy:

1. **Update the database:**
   ```sql
   -- Add new columns
   ALTER TABLE daily_aggregates
     ADD COLUMN IF NOT EXISTS offline_minutes INTEGER,
     ADD COLUMN IF NOT EXISTS peak_activity_hour INTEGER;

   -- Update the calculate_daily_metrics function
   -- Run the entire updated file: database/calculate_daily_metrics_function.sql
   ```

2. **Recalculate existing metrics** to populate new columns:
   ```sql
   SELECT calculate_daily_metrics('ESP32C6_001', '2026-03-04');
   SELECT calculate_daily_metrics('ESP32C6_001', '2026-03-03');
   -- etc for past 7 days
   ```

3. **Build and deploy the mobile app:**
   ```bash
   cd pictureFrame/software/moveometer_app
   flutter build apk  # For Android
   flutter build ios  # For iOS
   ```

### Future Enhancements:

- Add weekly/monthly trend charts
- Show baseline comparison ("10% above your average")
- Add notifications for significant changes
- Export daily reports as PDF
- Add date picker to view any historical day
- Show comparison between multiple days

## Files Modified

- `database/add_new_metrics_columns.sql` (NEW)
- `database/calculate_daily_metrics_function.sql` (UPDATED)
- `lib/services/sensor_data_service.dart` (UPDATED)
- `lib/pages/day_detail_page.dart` (NEW)
- `lib/pages/device_detail_page.dart` (UPDATED)

## Testing Checklist

- [ ] Add new columns to database
- [ ] Update calculate_daily_metrics function
- [ ] Recalculate metrics for past 7 days
- [ ] Build Flutter app without errors
- [ ] Test on Android device
- [ ] Test on iOS device
- [ ] Verify today's metrics update in real-time
- [ ] Verify past days list shows correctly
- [ ] Verify tapping a day opens detail view
- [ ] Verify 24-hour graph displays correctly
- [ ] Verify motion score colors are correct

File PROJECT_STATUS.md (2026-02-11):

# moveOmeter Project - Complete Status Documentation

**Last Updated:** February 10, 2026
**Project Status:** Active Development - Core Features Complete, Testing & Optimization Phase

---

## Table of Contents

1. [Project Overview](#project-overview)
2. [System Architecture](#system-architecture)
3. [Completed Features](#completed-features)
4. [Current Capabilities](#current-capabilities)
5. [Recent Major Updates](#recent-major-updates)
6. [Known Issues & Limitations](#known-issues--limitations)
7. [Testing Status](#testing-status)
8. [Deployment Information](#deployment-information)
9. [Documentation Index](#documentation-index)

> **🤖 For AI Assistants:** See [AI_AGENT_GUIDE.md](./AI_AGENT_GUIDE.md) for comprehensive technical context, implementation patterns, and decision-making guidelines.

---

## Project Overview

**moveOmeter** is a comprehensive IoT elderly monitoring system that uses mmWave radar technology to provide non-invasive, privacy-preserving health and activity monitoring.

### Core Purpose
Monitor seniors in their homes to track:
- Movement patterns and activity levels
- Sleep quality and duration
- Presence detection and fall alerts
- Vital signs (heart rate, respiration)
- Daily activity metrics for caretaker oversight

### Key Differentiators
- **Privacy-first:** Uses radar technology (no cameras or wearables)
- **Non-invasive:** No user interaction required
- **Real-time:** Live data streaming and alerts
- **Multi-role:** Supports admins, employees, caretakers, and residents
- **Scalable:** Designed for 100 to 5M+ users

---

## System Architecture

### Hardware Layer
**ESP32-C6 Feather + DFRobot SEN0623 mmWave Sensor**

```
┌─────────────────────────────────────────┐
│   ESP32-C6 Feather                      │
│   ├─ WiFi 2.4GHz (internet connection)  │
│   ├─ GPIO16 (TX) → mmWave RX            │
│   ├─ GPIO17 (RX) → mmWave TX            │
│   ├─ USB Serial (115200 debugging)      │
│   └─ OTA Update Capable                 │
└─────────────────────────────────────────┘
         ↓ WiFi Upload
┌─────────────────────────────────────────┐
│   DFRobot SEN0623 mmWave Sensor         │
│   ├─ Human presence detection           │
│   ├─ Movement & distance tracking       │
│   ├─ Vital signs (heart rate, respir.)  │
│   ├─ Sleep monitoring                   │
│   ├─ Fall detection                     │
│   └─ UART communication (9600 baud)     │
└─────────────────────────────────────────┘
```

**Firmware:**
- Platform: Arduino (C++)
- Current Version: 1.0.0
- Location: `/pictureFrame/software/mmWave_Supabase_collector/`

**Key Features:**
- Dual collection modes (Quick/Medium) - configurable remotely
- Smart keep-alive (30s when no presence, full data when presence detected)
- Periodic config checks (60s) to sync settings from cloud
- OTA firmware update capability (1-hour check interval)
- Device timestamp tracking for accurate time series data
- WiFi auto-reconnect with retry logic
- Fall detection with 30s monitoring even when no presence

### Backend Layer
**Supabase (PostgreSQL + Auth + Storage + Realtime)**

**Database Tables:**
```
moveometers (device registry)
  ├─ device_id, location, firmware_version
  ├─ data_collection_mode (quick/medium)
  ├─ ota_check_interval_ms, ota_status
  └─ last_ota_check, last_ota_update

mmwave_sensor_data (time series data)
  ├─ 40+ sensor fields
  ├─ device_timestamp (when recorded)
  ├─ created_at (when uploaded)
  └─ data_type (keep_alive vs full)

user_profiles (authentication)
  ├─ id, email, full_name
  ├─ role (admin/employee/caretaker/caretakee)
  ├─ is_active, mfa_enabled
  └─ last_login

device_access (permissions)
  ├─ user_id, device_id
  └─ access_level (view/control/admin)

firmware_updates (OTA)
  ├─ version, device_model
  ├─ download_url, md5_checksum
  └─ mandatory, release_notes

audit_log (security)
  ├─ user_id, action, resource
  └─ success, error_message

annotations (timeline notes)
  ├─ user_id, device_id
  ├─ annotation_time, text
  └─ annotation_type (manual/automatic)
```

**Row Level Security (RLS):**
- ✅ Admin/employee: full access to all devices
- ✅ Caretaker: access only to assigned devices via device_access
- ✅ Caretakee: access only to own linked devices
- ✅ Public insert allowed for sensor data (device uploads)
- ✅ Audit logging for all security-sensitive actions

**Realtime Subscriptions:**
- Live data updates via WebSocket
- Instant chart updates when new sensor data arrives
- No polling required

### Frontend Layer
**Web Dashboard (Vanilla JavaScript)**

**Pages:**
- `index.html` - Main dashboard with real-time charts and metrics
- `login.html` - Authentication (email/password, supports MFA/passkey)
- `admin.html` - Admin panel for user/device management
- `test_timeline.html` - Timeline testing and debugging

**Key Features:**
- Real-time data visualization (Chart.js)
- Three timeline views: 1-hour, 12-hour, 24-hour
- Time-based data aggregation (reduces rendering load by 83-97%)
- Automatic mode change annotations
- Device online/offline status indicators
- Role-based access control
- Responsive design (works on mobile/tablet/desktop)

**Deployment:**
- Hosted on Digital Ocean droplet: http://167.71.107.200
- Nginx web server
- Deployment script: `/deployment/deploy.sh`

---

## Completed Features

### ✅ Hardware & Firmware
- [x] ESP32-C6 + SEN0623 mmWave sensor integration
- [x] WiFi connectivity with auto-reconnect
- [x] Direct Supabase upload via ESPSupabase library
- [x] Dual collection modes (Quick: minimal, Medium: full sensors)
- [x] Remote configuration via cloud (60s sync interval)
- [x] Smart keep-alive optimization (97% bandwidth reduction when idle)
- [x] Fall detection monitoring (30s checks even when no presence)
- [x] OTA firmware update infrastructure
- [x] Device timestamp tracking
- [x] Human presence detection (eHumanPresence mapping)
- [x] Automatic retry logic for failed uploads

### ✅ Backend & Database
- [x] Supabase project setup with PostgreSQL
- [x] Complete database schema with indexes
- [x] Row Level Security policies for all roles
- [x] Authentication system (email/password)
- [x] User profile management with roles
- [x] Device access control system
- [x] Automatic profile creation trigger
- [x] Audit logging for security events
- [x] Firmware updates table for OTA
- [x] Annotations table for timeline notes
- [x] Realtime subscriptions enabled

### ✅ Frontend & Dashboard
- [x] Real-time data visualization dashboard
- [x] Authentication guard (redirects to login if not authenticated)
- [x] Role-based UI elements (show admin button only to admin/employee)
- [x] Three timeline views (1-hour, 12-hour, 24-hour)
- [x] Time-based data aggregation for performance
- [x] Query ordering fix (get recent data first, not old data)
- [x] Device timestamp usage for accurate time series
- [x] Automatic mode change annotations
- [x] Device online/offline status indicator
- [x] Metrics hide when device offline
- [x] Manual annotation capability
- [x] Admin panel for user/device/audit management
- [x] Login/signup UI with proper error handling

### ✅ Deployment & DevOps
- [x] Digital Ocean droplet setup
- [x] Nginx web server configuration
- [x] Deployment script with proper paths
- [x] Database migration scripts
- [x] Setup documentation (README.md, QUICKSTART.md)

---

## Current Capabilities
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

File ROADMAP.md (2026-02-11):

# moveOmeter Development Roadmap

**Last Updated:** February 10, 2026
**Planning Horizon:** February 2026 - August 2026

> **🤖 For AI Assistants:** See [AI_AGENT_GUIDE.md](./AI_AGENT_GUIDE.md) for technical implementation details and best practices when working on roadmap items.

---

## Table of Contents

1. [Current Sprint (Next 2 Weeks)](#current-sprint-next-2-weeks)
2. [Short-Term Goals (Next Month)](#short-term-goals-next-month)
3. [Medium-Term Objectives (Next Quarter)](#medium-term-objectives-next-quarter)
4. [Long-Term Vision (Next 6-12 Months)](#long-term-vision-next-6-12-months)
5. [Technical Debt](#technical-debt)
6. [Feature Wishlist](#feature-wishlist)
7. [Scaling Roadmap](#scaling-roadmap)

---

## Current Sprint (Next 2 Weeks)
**Timeline:** February 10-23, 2026
**Focus:** Testing, Bug Fixes, Essential Features

### 🔴 Critical Priority

#### 1. OTA Firmware Update Testing
**Status:** Infrastructure complete, needs end-to-end testing
**Effort:** 2-4 hours
**Prerequisites:** ESP32-C6 device available, Supabase storage configured
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

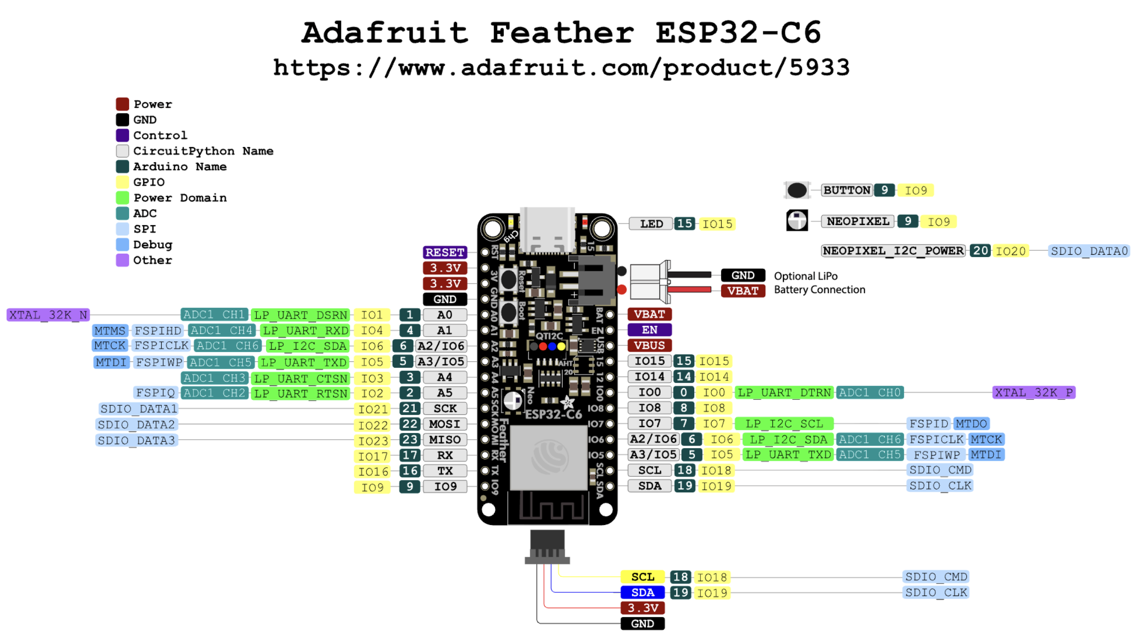
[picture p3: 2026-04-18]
pictureFrame/electrical/part libraries/Adafruit ESP32 C6/Adafruit ESP32-C6 pinout.png

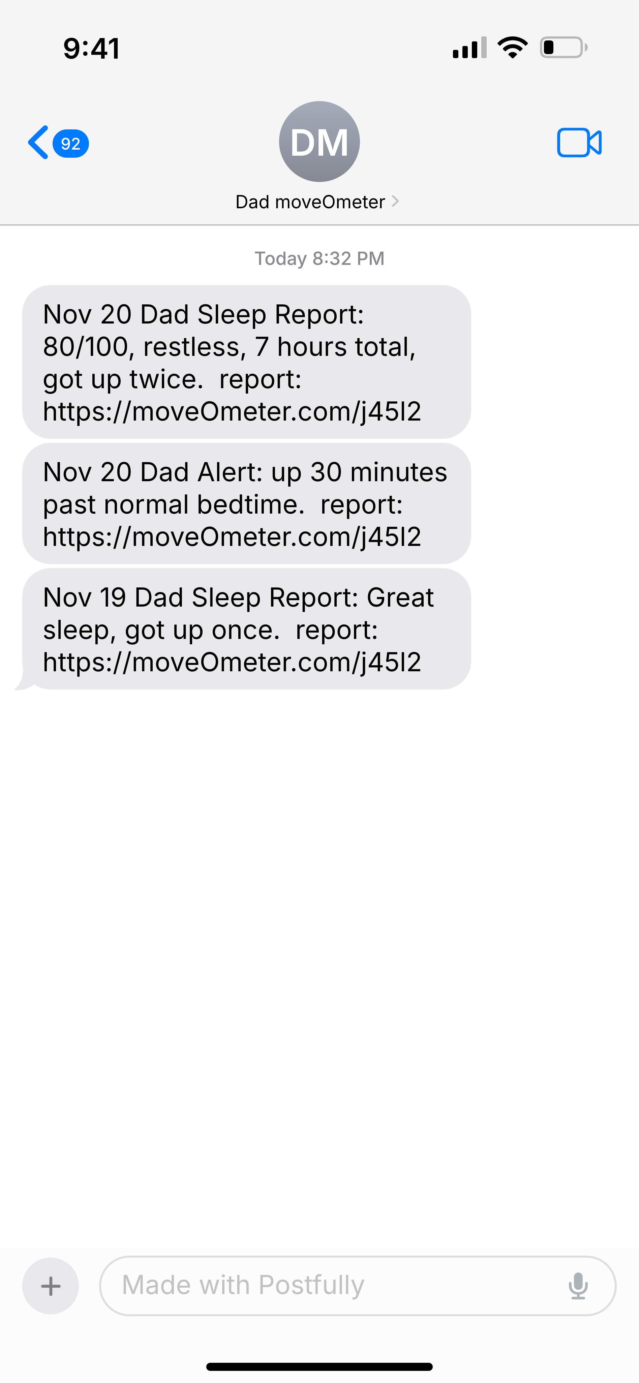
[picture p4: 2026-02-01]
2025_11_pitchdeck/postfully-text-message-1764985533228.png

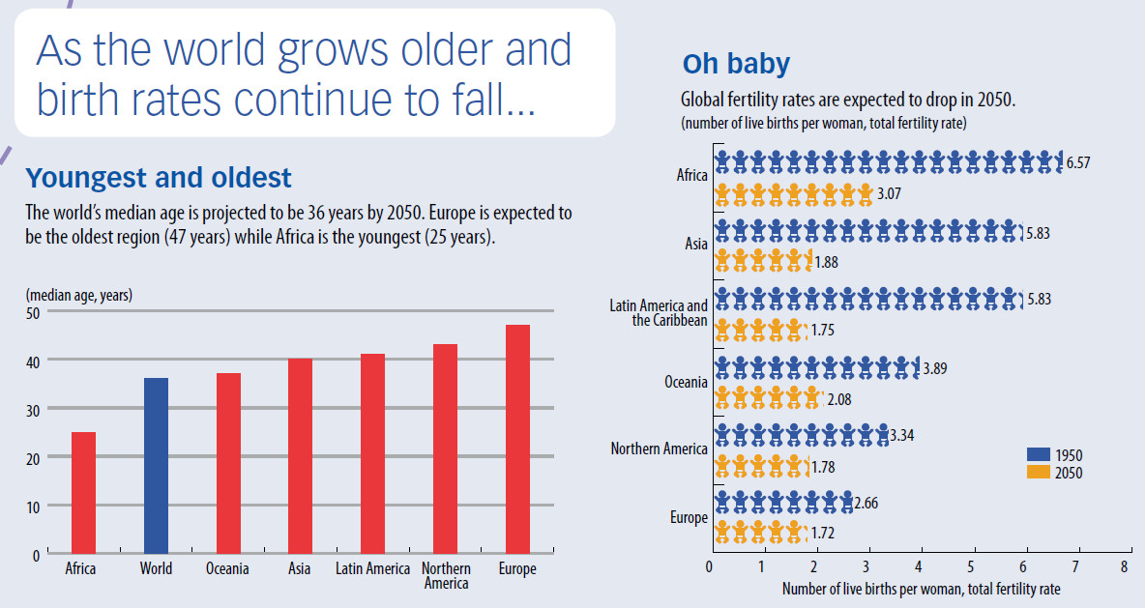
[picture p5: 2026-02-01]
2025_11_pitchdeck/birthratesfalling.jpg

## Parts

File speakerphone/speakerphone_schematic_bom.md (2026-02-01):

# Elderly Speakerphone - Quick Reference Schematic & BOM

## Wiring Diagram

```
                                    ┌─────────────────────────────────┐
                                    │         ESP32-S3-WROOM-1        │
                                    │            (8MB PSRAM)          │
                                    │                                 │
    ┌───────────────┐               │  GPIO4  ←── I2S_MIC_BCK        │
    │   INMP441 #1  │───────────────┤  GPIO5  ←── I2S_MIC_WS         │
    │   (Left Mic)  │  I2S          │  GPIO6  ←── I2S_MIC_DATA       │
    │  L/R = GND    │               │                                 │
    └───────────────┘               │  GPIO15 ──→ I2S_SPK_BCK        │
                                    │  GPIO16 ──→ I2S_SPK_WS         │
    ┌───────────────┐               │  GPIO17 ──→ I2S_SPK_DATA       │
    │   INMP441 #2  │───────────────┤                                 │
    │   (Right Mic) │  I2S          │  GPIO18 ──→ I2C_SDA (amp ctrl) │
    │  L/R = VDD    │               │  GPIO19 ──→ I2C_SCL            │
    └───────────────┘               │                                 │
                                    │  GPIO21 ──→ NFC_SDA            │
                                    │  GPIO22 ──→ NFC_SCL            │
                                    │                                 │
    ┌───────────────┐               │  GPIO35 ←── BUTTON (arcade)    │
    │   ES8311      │───────────────┤  GPIO36 ──→ LED_RING (WS2812)  │
    │ (Echo Ref ADC)│  I2S/I2C      │                                 │
    │               │               │  GPIO1/GPIO2 ←→ UART (A7670G)  │
    └───────────────┘               │                                 │
                                    │  EN ←── Power Button            │
                                    └─────────────────────────────────┘
                                                    │
                                                    │ I2S
                                                    ▼
                                    ┌─────────────────────────────────┐
                                    │         TAS5805M                │
                                    │      (10W Class D Amp)          │
                                    │                                 │
                                    │  PVDD ←── 12V                   │
                                    │  DVDD ←── 3.3V                  │
                                    │  GND  ←── GND                   │
                                    │                                 │
                                    │  OUTP ──┬──→ Speaker (+)        │
                                    │  OUTN ──┴──→ Speaker (-)        │
                                    │                                 │
                                    │  PDN  ←── ESP32 GPIO (enable)   │
                                    │  FAULT ──→ ESP32 GPIO (status)  │
                                    └─────────────────────────────────┘
                                                    │
                                                    │ BTL Output
                                                    ▼
                                    ┌─────────────────────────────────┐
                                    │     3" Full-Range Speaker       │
                                    │     (4Ω or 8Ω, 10W)            │
                                    │                                 │
                                    │     In sealed wood enclosure    │
                                    │     ~0.5-1.0 liter volume       │
                                    └─────────────────────────────────┘

    ┌───────────────┐               ┌─────────────────────────────────┐
    │   A7670G      │←── UART ─────→│         ESP32-S3               │
    │  LTE Modem    │               │                                 │
    │               │               │  Audio via I2S or PCM:          │
    │  VoLTE Audio: │               │  - A7670 has PCM interface      │
    │  PCM_CLK      │←─────────────→│  GPIO7                          │
    │  PCM_SYNC     │←─────────────→│  GPIO8                          │
    │  PCM_DIN      │←──────────────│  GPIO9  (ESP32 → Modem)         │
    │  PCM_DOUT     │──────────────→│  GPIO10 (Modem → ESP32)         │
    │               │               │                                 │
    │  SIM Slot     │               │                                 │
    │  Antenna      │               │                                 │
    └───────────────┘               └─────────────────────────────────┘

    ┌───────────────┐
    │   PN532       │
    │  NFC Reader   │──── I2C ────→ ESP32-S3 (GPIO21/22)
    │               │
    │  Card Slot    │←── RFID/NFC Cards with contact photos
    └───────────────┘

    ┌───────────────┐
    │  60mm Arcade  │
    │   Button      │──── GPIO35 (with internal pullup)
    │  w/ LED Ring  │
    │               │
    │  LED Ring     │──── GPIO36 (WS2812 data)
    └───────────────┘
```

---

## Bill of Materials

### Core Electronics

| Qty | Part | Description | Part Number | Price | Source |
|-----|---|---|---|---|---|
| 1 | ESP32-S3 Module | 8MB PSRAM, 16MB Flash | ESP32-S3-WROOM-1-N16R8 | $4.50 | LCSC, Mouser |
| 1 | LTE Modem | Cat-1 with VoLTE | SIMCom A7670G or LILYGO T-A7670G | $25-35 | AliExpress, Amazon |
| 2 | MEMS Microphone | I2S digital output | INMP441 (breakout) | $2 ea | Amazon, AliExpress |
| 1 | Audio Codec | For echo reference | ES8311 (breakout) | $3 | AliExpress |
| 1 | Class D Amplifier | 10W I2S input | TAS5805M (module) | $12 | Amazon, AliExpress |
| 1 | NFC Reader | For contact cards | PN532 (breakout) | $5 | Amazon, AliExpress |

### Audio

| Qty | Part | Description | Part Number | Price | Source |
|-----|---|---|---|---|---|
| 1 | Speaker | 3" full-range, 8Ω, 10W | Tang Band W3-881SJ | $20 | Parts Express |
| 1 | Enclosure | Wood box, ~0.7L | Custom or DIY | $10-30 | - |
| 1 | Damping | Polyester fill | Polyfill | $5 | Parts Express |

### User Interface

| Qty | Part | Description | Part Number | Price | Source |
|-----|---|---|---|---|---|
| 1 | Arcade Button | 60mm illuminated, red | Adafruit 1185 | $5 | Adafruit |
| 1 | LED Ring | 12-LED WS2812 | Adafruit 1643 | $8 | Adafruit |
| 1 | Display | Small OLED (optional) | SSD1306 128x64 | $5 | Amazon |
| 10 | NFC Cards | Blank NTAG215 | NTAG215 cards | $0.50 ea | Amazon |

### Power

| Qty | Part | Description | Part Number | Price | Source |
|-----|---|---|---|---|---|
| 1 | Power Supply | 12V 2A DC adapter | Generic | $8 | Amazon |
| 1 | Buck Converter | 12V → 5V, 3A | LM2596 or MP1584 | $2 | Amazon |
| 1 | LDO | 5V → 3.3V, 500mA | AMS1117-3.3 | $0.20 | LCSC |
| 1 | Battery (optional) | 18650 Li-ion | Samsung 30Q | $5 | - |
| 1 | Charger (optional) | TP4056 with protection | TP4056 module | $1 | AliExpress |

### Connectors & Misc

| Qty | Part | Description | Price |
|-----|---|---|---|
| 1 | SIM Card Holder | Nano-SIM | $0.50 |
| 1 | USB-C Connector | For programming/power | $0.50 |
| 1 | DC Barrel Jack | 5.5x2.1mm | $0.30 |
| 2 | 4-pin JST | For mic connections | $0.20 |
| 1 | 2-pin JST | For speaker | $0.10 |
| - | PCB | Custom 2-layer | $5-10 |
| - | Misc capacitors, resistors | 0603 passives | $2 |

### Total Estimated BOM

| Category | Cost |
|---|---|
| Core Electronics | ~$55 |
| Audio (speaker + enclosure) | ~$35 |
| User Interface | ~$25 |
| Power | ~$15 |
| Connectors & Misc | ~$10 |
| **TOTAL** | **~$140** |

**Target Retail:** $199-249 (one-time, no subscription required)

---

## Simpler Development Path

### Option A: Start with Dev Kit

**ESP32-S3-Korvo-2** (~$50)
- Already has: 2-mic array, codec, amp, speaker
- AEC reference signal pre-routed
- Just add: A7670G modem, NFC reader, button, enclosure

### Option B: ESP32-S3-BOX-3 (~$45)
- Built-in display, speaker, mics
- Good for rapid prototyping
- Add: A7670G modem, NFC reader, bigger speaker

---

## Key Connections Summary

### I2S Mic Input (from INMP441 array)
```
ESP32-S3         INMP441 #1 (L)    INMP441 #2 (R)
---------        --------------    --------------
GPIO4 (BCLK)  →  SCK            →  SCK
GPIO5 (WS)    →  WS             →  WS  
GPIO6 (DIN)   ←  SD             ←  SD
3.3V          →  VDD            →  VDD
GND           →  GND            →  GND
              →  L/R = GND      →  L/R = 3.3V
```

### I2S Speaker Output (to TAS5805M)
```
ESP32-S3           TAS5805M
---------          --------
GPIO15 (BCLK)   →  SCLK
GPIO16 (WS)     →  LRCLK
GPIO17 (DOUT)   →  SDIN
GPIO18 (SDA)    →  SDA (I2C config)
GPIO19 (SCL)    →  SCL
3.3V            →  DVDD
12V             →  PVDD
GND             →  GND
```

### A7670G LTE Modem (UART + PCM)
```
ESP32-S3           A7670G
---------          ------
GPIO1 (TX)      →  RXD
GPIO2 (RX)      ←  TXD
GPIO3           →  PWRKEY
GPIO7           ↔  PCM_CLK
GPIO8           ↔  PCM_SYNC
GPIO9           →  PCM_DIN (ESP32 audio out)
GPIO10          ←  PCM_DOUT (modem audio in)
```

---

## Software Stack

```
┌─────────────────────────────────────────────────────────────┐
│                    APPLICATION LAYER                        │
│  - Phone call management (dial, answer, hangup)            │
│  - Contact management (NFC cards ↔ phone numbers)          │
│  - LED feedback (calling, connected, error states)         │
│  - Button handler (press = next contact, hold = hangup)    │
└─────────────────────────────────────────────────────────────┘
                              │
┌─────────────────────────────────────────────────────────────┐
│                    AUDIO PIPELINE                           │
│  ESP-ADF with:                                             │
│  - algorithm_stream (AEC + NS + AGC)                       │
│  - i2s_stream (mic input, speaker output)                  │
│  - Audio routing to/from LTE modem PCM                     │
└─────────────────────────────────────────────────────────────┘
                              │
┌─────────────────────────────────────────────────────────────┐
│                    CELLULAR LAYER                           │
│  AT Commands for A7670G:                                   │
│  - ATD<number>;  (dial)                                    │
│  - ATA          (answer)                                   │
│  - ATH          (hangup)                                   │
│  - AT+CLCC      (call status)                              │
│  - AT+CPCMREG=1 (enable PCM audio)                         │
└─────────────────────────────────────────────────────────────┘
```

---

## Next Steps

1. **Order ESP32-S3-Korvo-2** for audio development
2. **Order LILYGO T-A7670G** for cellular integration  
3. **Test AEC** with ESP-ADF voip example
4. **Design NFC card system** with PN532
5. **Prototype enclosure** with selected speaker
6. **Integrate systems** on custom PCB

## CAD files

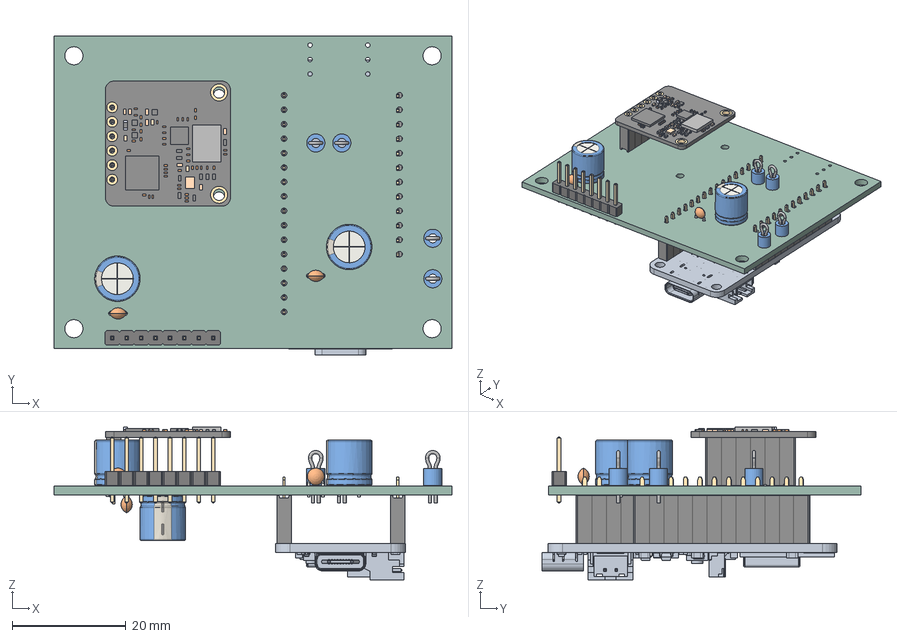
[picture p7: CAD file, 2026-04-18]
pictureFrame/electrical/moveOmeterV1/moveOmeterV1_fused.step
70.0 x 56.1 x 26.8 mm
TestPoint_Loop_D2.60mm_Drill1.6mm_Beaded x 4
PinHeader_1x08_P2.54mm_Vertical
SEN0623
PPPC021LFBN-RC_C06
Pin - Gold x 34
C_Disc_D3.0mm_W2.0mm_P2.50mm x 3
CP_Radial_D8.0mm_P3.50mm x 3
moveOmeterV1_fused 1.14.1
PPPC021LFBN-RC_C12
PPPC021LFBN-RC_C16
moveOmeterV1_PCB

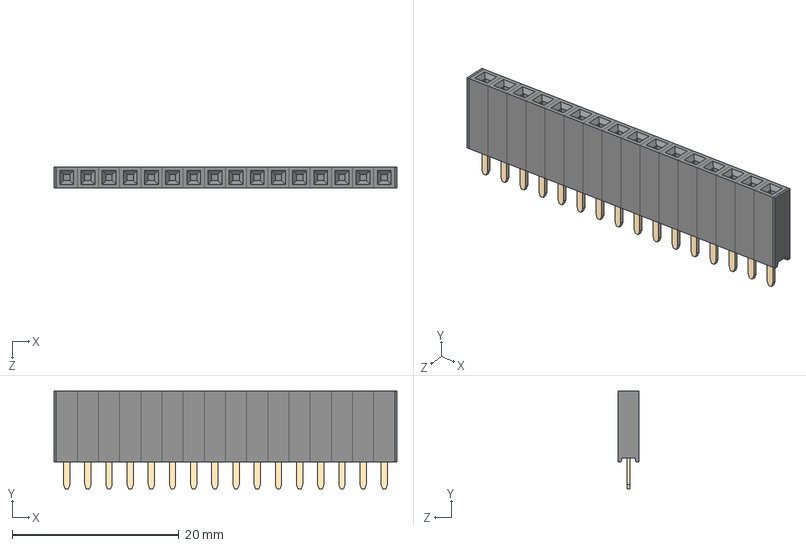
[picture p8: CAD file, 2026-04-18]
pictureFrame/electrical/part libraries/Adafruit ESP32 C6/PPPC161LFBN-RC.STEP
41.1 x 11.7 x 2.54 mm
PPPC021LFBN-RC_C16
Pin - Gold x 16

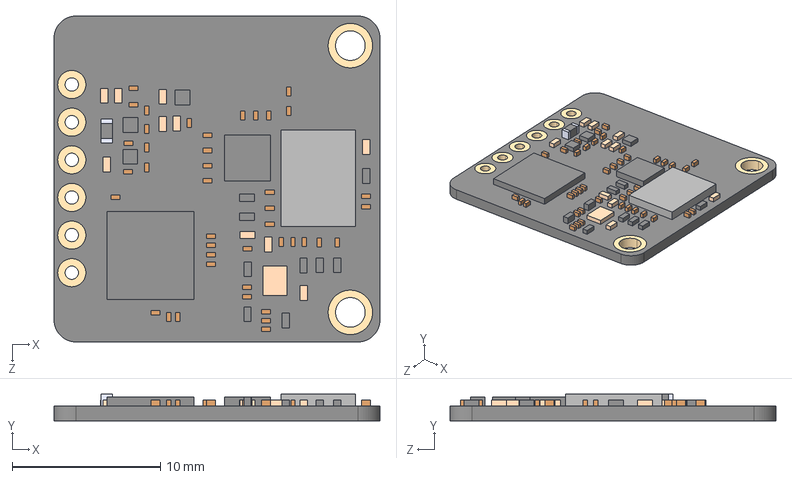
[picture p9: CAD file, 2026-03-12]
pictureFrame/electrical/part libraries/mmWaveDFRobot/SEN0623/SEN0623.step
22.0 x 1.79 x 22.0 mm

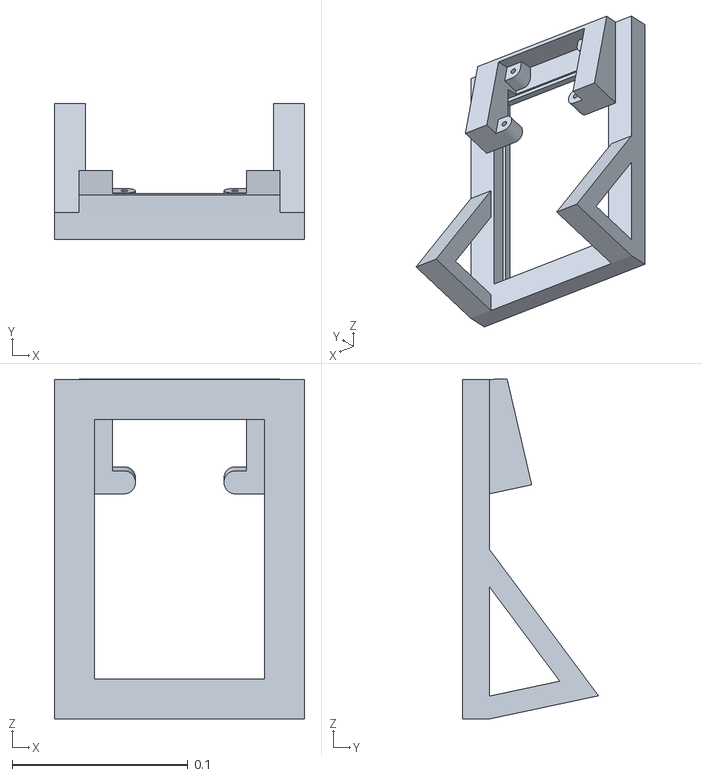
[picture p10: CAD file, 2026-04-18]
pictureFrame/hardware/2026_04_06_Version0_01/2026_04_06_pictureFrame_unitMeterv0.01.stl
0.142 x 0.0774 x 0.193

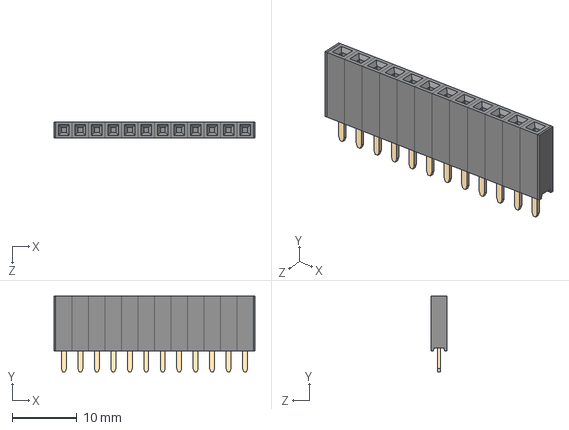
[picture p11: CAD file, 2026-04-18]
pictureFrame/electrical/part libraries/Adafruit ESP32 C6/PPPC121LFBN-RC.STEP
31.0 x 11.7 x 2.54 mm
PPPC021LFBN-RC_C12
Pin - Gold x 12

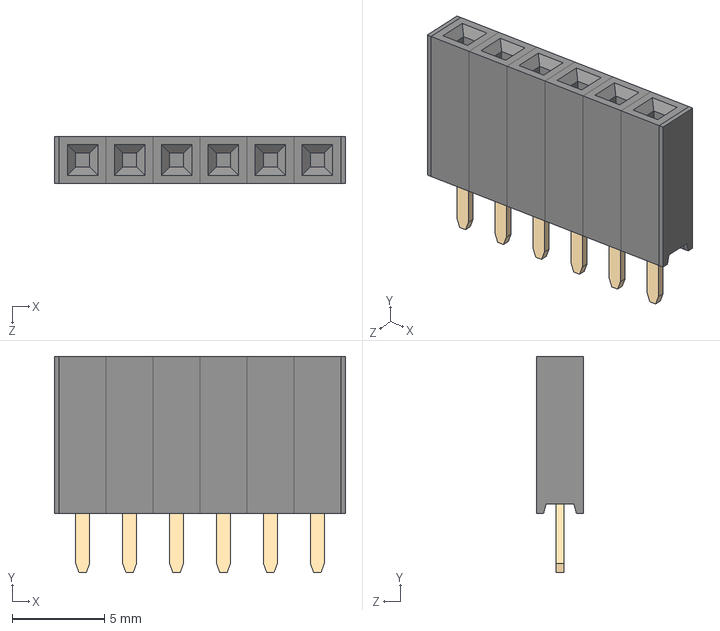
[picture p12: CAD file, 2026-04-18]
pictureFrame/electrical/part libraries/Adafruit ESP32 C6/PPPC061LFBN-RC.STEP
15.7 x 11.7 x 2.54 mm
PPPC021LFBN-RC_C06
Pin - Gold x 6

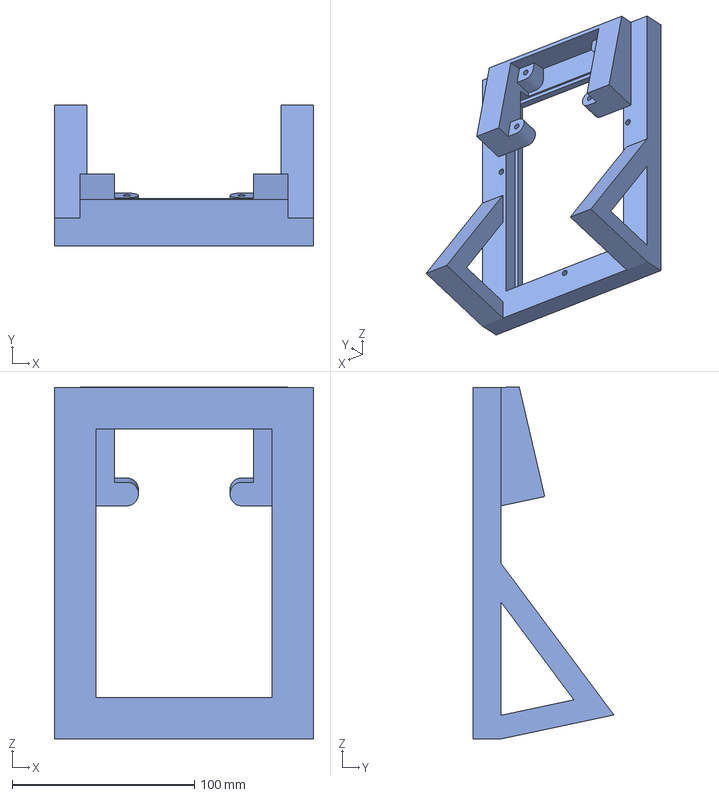
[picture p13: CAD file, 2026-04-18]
pictureFrame/hardware/2026_04_06_Version0_01/2026_04_06_pictureFrame_v0.02.3mf
142.2 x 77.4 x 193.2 mm

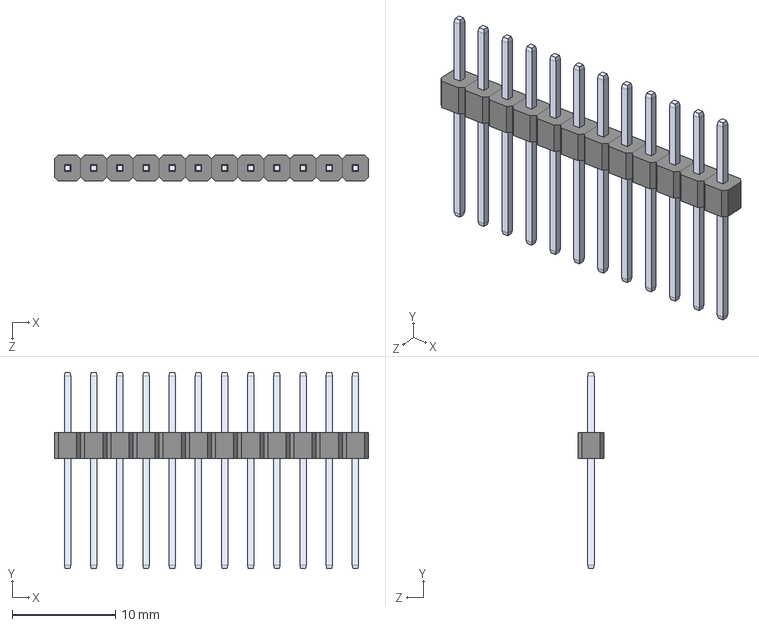
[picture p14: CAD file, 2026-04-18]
pictureFrame/electrical/part libraries/Adafruit ESP32 C6/PEC12SADN.STEP
30.5 x 19.1 x 2.54 mm
GBC36SAAN_GC12S
Pin - Tin_AD x 12

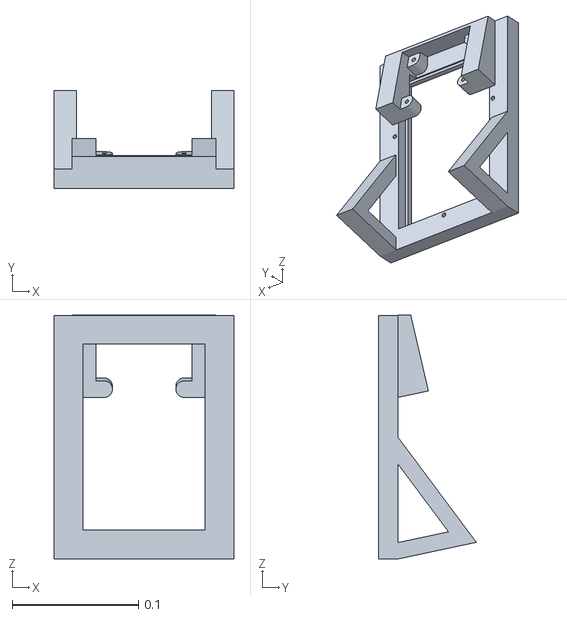
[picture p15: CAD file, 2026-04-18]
pictureFrame/hardware/2026_04_06_Version0_01/2026_04_06_pictureFrame_unitMeterv0.02.stl
0.142 x 0.0774 x 0.193

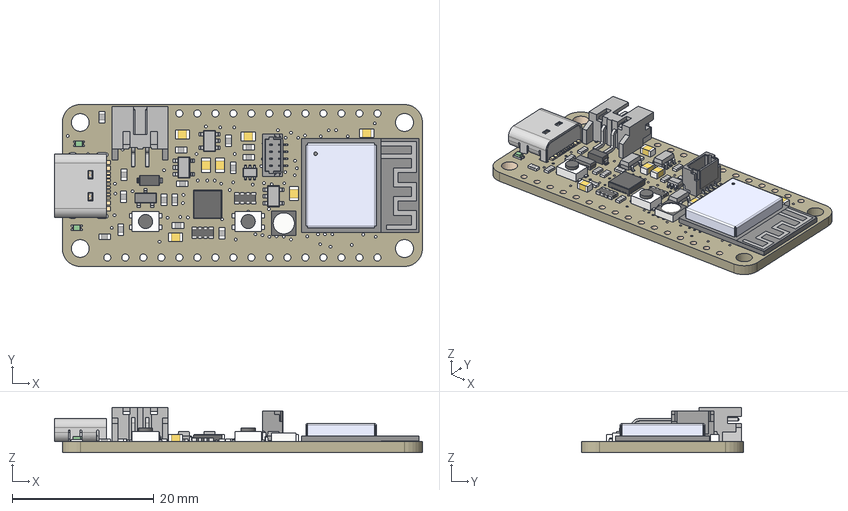
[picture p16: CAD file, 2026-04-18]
pictureFrame/electrical/part libraries/Adafruit ESP32 C6/5400 ESP32 Feather V2.step
51.9 x 22.9 x 6.37 mm
Board
10uF x 7
AP2112-3.3 x 2
MBR540
JSTPH
MCP73831T-2ACI/OT
RED x 2
1uF x 15
KMR2 x 2
DMG3415U
47K x 2
ESP32-PICO-MINI-02MINI
WS2812B3535
STEMMA_I2C_QTRA
TPB1,27 x 2
USB Type C
CP2102N-24
DUAL NPN

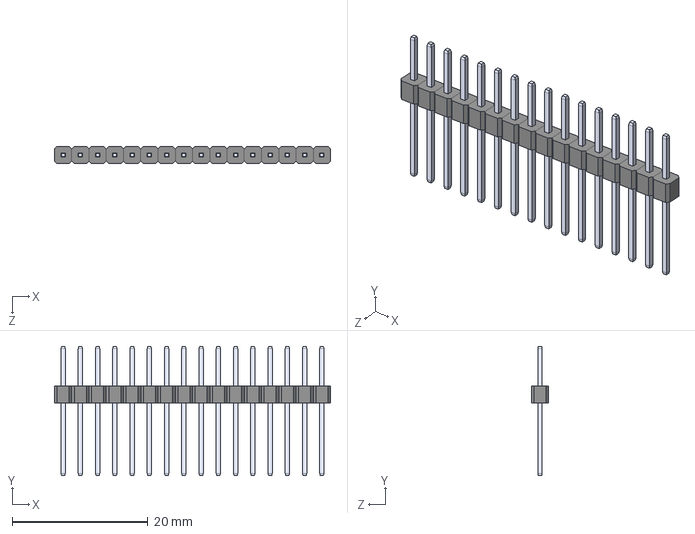
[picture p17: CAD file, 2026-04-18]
pictureFrame/electrical/part libraries/Adafruit ESP32 C6/PEC16SADN.STEP
40.6 x 19.1 x 2.54 mm
GBC36SAAN_GC16S
Pin - Tin_AD x 16

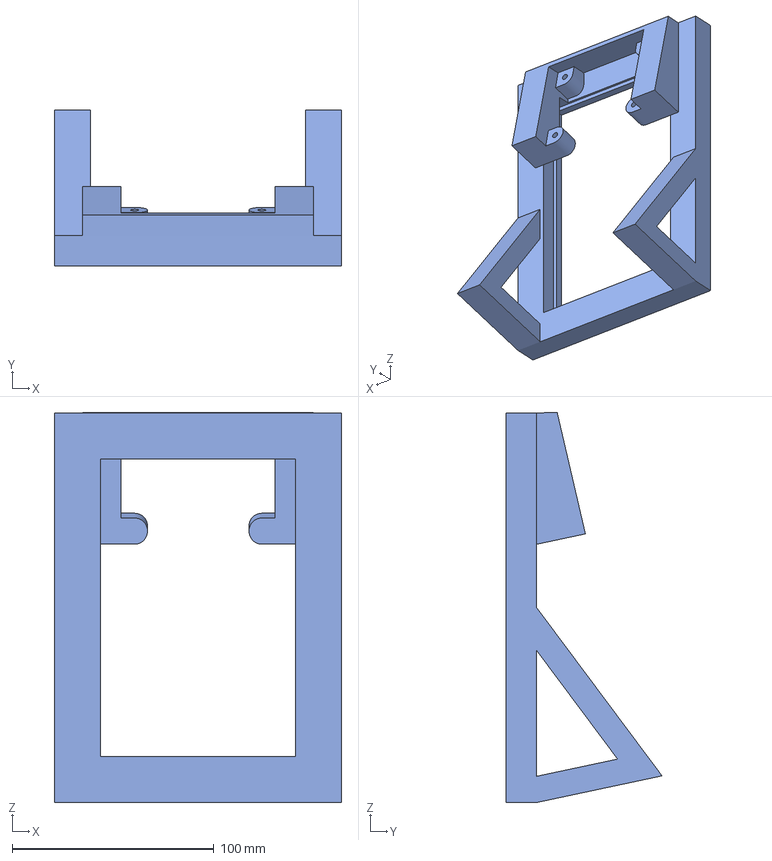
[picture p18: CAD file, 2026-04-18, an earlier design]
pictureFrame/hardware/2026_04_06_Version0_01/2026_04_06_pictureFrame_v0.01.3mf
142.2 x 77.4 x 193.2 mm

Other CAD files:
pictureFrame/electrical/moveOmeterV1/moveOmeterV1.step

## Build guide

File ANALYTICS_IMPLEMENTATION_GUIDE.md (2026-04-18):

# Analytics Implementation Guide

This guide explains how to implement and use the moveOmeter analytics system for tracking user behavior on both web and mobile platforms.

## Overview

The analytics system tracks:
- **User sessions** (login times, duration, activity)
- **User actions** (button clicks, page views, interactions)
- **App usage** (version tracking, platform, device info)
- **Aggregated metrics** (total logins, average session duration, popular features)

## Database Setup

### 1. Create Analytics Tables

Run this SQL in Supabase SQL Editor:

```bash
/database/create_analytics_tables.sql
```

This creates:
- `user_sessions` - Web dashboard sessions
- `user_actions` - Detailed action log for web
- `user_login_stats` - Aggregated user statistics
- `app_sessions` - Mobile app sessions
- `app_actions` - Detailed action log for mobile
- `app_usage_stats` - Aggregated app usage stats

## Web Dashboard Implementation

### 2. Add Analytics Script to Dashboard

Add to `web/dashboard/index.html` before closing `</head>`:

```html
<script src="analytics.js"></script>
```

### 3. Initialize Analytics After Login

In `web/dashboard/dashboard.js`, after successful login:

```javascript
// After user logs in successfully
const { data: { user } } = await supabase.auth.getUser();
if (user) {
    // Initialize analytics
    initializeAnalytics(supabase, user.id);
}
```

### 4. Track User Actions

Add tracking calls throughout your dashboard code:

```javascript
// Track button clicks
document.getElementById('admin-btn').addEventListener('click', () => {
    trackAction('button_click', 'navigation', 'admin_button');
    // ... existing code
});

// Track mode switches
function switchMode(newMode) {
    trackAction('mode_switch', 'settings', 'operational_mode', newMode);
    // ... existing code
}

// Track chart interactions
charts.timeline12Hour.options.plugins.zoom.onZoomComplete = function() {
    trackAction('chart_interaction', 'data_view', 'timeline_12h', 'zoom');
};

// Track device views
function viewDevice(deviceId) {
    trackAction('device_view', 'device_management', deviceId);
    // ... existing code
}

// Track annotation creation
function createAnnotation(type) {
    trackAction('annotation_create', 'data_annotation', type);
    // ... existing code
}
```

## Mobile App Implementation

### 5. Import Analytics Service

Add to your Flutter page imports:

```dart
import '../services/analytics_service.dart';
```

### 6. Start Session on App Launch

In `main.dart` or your main app widget:

```dart
@override
void initState() {
  super.initState();
  // Start analytics session after login
  analyticsService.startSession();
}

@override
void dispose() {
  // End session when app closes
  analyticsService.endSession();
  super.dispose();
}
```

### 7. Track Screen Views

Add to the `initState()` of each page:

```dart
@override
void initState() {
  super.initState();
  analyticsService.trackScreenView('HousesPage');
}
```

### 8. Track User Actions

Add tracking calls throughout your app:

```dart
// Track button taps
ElevatedButton(
  onPressed: () {
    analyticsService.trackButtonTap('add_house_button',
      screenName: 'HousesPage');
    // ... existing code
  },
  child: Text('Add House'),
)

// Track device actions
void addDevice() async {
  analyticsService.trackDeviceAction('add_device', deviceId,
    screenName: 'DevicesPage');
  // ... existing code
}

// Track BLE provisioning steps
void startProvisioning() {
  analyticsService.trackBLEProvisioning('start',
    deviceId: deviceId,
    screenName: 'ScanDevicesPage');
  // ... existing code
}

// Track house views
void viewHouse(String houseId) {
  analyticsService.trackHouseView(houseId,
    screenName: 'HouseDayDetailPage');
  // ... existing code
}

// Track login/logout
void login() async {
  // ... login code
  await analyticsService.trackLogin();
  await analyticsService.startSession();
}

void logout() async {
  await analyticsService.trackLogout();
  // ... logout code
}
```

## Viewing Analytics Data

### Query Examples

**Most active users (total logins):**
```sql
SELECT
  u.email,
  s.total_logins,
  s.last_login_at,
  s.average_session_duration_seconds / 60 as avg_session_minutes
FROM user_login_stats s
JOIN auth.users u ON u.id = s.user_id
ORDER BY s.total_logins DESC
LIMIT 10;
```

**Recent user actions:**
```sql
SELECT
  u.email,
  a.action_type,
  a.action_target,
  a.created_at
FROM user_actions a
JOIN auth.users u ON u.id = a.user_id
ORDER BY a.created_at DESC
LIMIT 50;
```

**App version distribution:**
```sql
SELECT
  app_platform,
  current_version,
  COUNT(*) as user_count
FROM app_usage_stats
GROUP BY app_platform, current_version
ORDER BY app_platform, user_count DESC;
```

**Active sessions now:**
```sql
SELECT
  u.email,
  s.session_start,
  s.page_views,
  s.actions_count,
  s.browser,
  s.device_type
FROM user_sessions s
JOIN auth.users u ON u.id = s.user_id
WHERE s.session_end IS NULL
  AND s.session_start > NOW() - INTERVAL '1 hour'
ORDER BY s.session_start DESC;
```

**Popular features (most clicked buttons):**
```sql
SELECT
  action_target,
  COUNT(*) as click_count
FROM user_actions
WHERE action_type = 'button_click'
  AND created_at > NOW() - INTERVAL '7 days'
GROUP BY action_target
ORDER BY click_count DESC
LIMIT 10;
```

**App engagement metrics:**
```sql
SELECT
  app_platform,
  COUNT(DISTINCT user_id) as active_users,
  AVG(total_sessions) as avg_sessions_per_user,
  AVG(total_session_duration_seconds / 60) as avg_total_minutes
FROM app_usage_stats
WHERE last_used_at > NOW() - INTERVAL '30 days'
GROUP BY app_platform;
```

## Tracked Metrics

### Web Dashboard

| Metric | Description |
|---|---|
| **Session Start/End** | When user logs in/out or closes tab |
| **Session Duration** | Total time spent in dashboard |
| **Page Views** | Number of different pages/views |
| **Actions Count** | Total interactions (clicks, zooms, etc.) |
| **Browser/OS** | User's browser and operating system |
| **Device Type** | Desktop, tablet, or mobile |
| **IP Address** | User's IP for geo-location |
| **Button Clicks** | Which buttons were clicked |
| **Chart Interactions** | Zoom, pan, hover on charts |
| **Mode Switches** | Sleep ↔ Fall Detection mode changes |
| **Device Views** | Which devices were viewed |

### Mobile App

| Metric | Description |
|---|---|
| **Session Start/End** | When app opens/closes |
| **Session Duration** | Total time in app |
| **App Version** | Which version user is on |
| **Platform** | iOS or Android |
| **Device Model** | Phone/tablet model |
| **OS Version** | iOS/Android version |
| **Screens Viewed** | Number of screens navigated |
| **Actions Count** | Total interactions |
| **Button Taps** | Which buttons were tapped |
| **Screen Views** | Which screens were viewed |
| **Device Actions** | Add, remove, configure devices |
| **BLE Provisioning** | Setup flow tracking |

## Privacy & Security

- All analytics data is user-specific and protected by RLS (Row Level Security)
- Users can only see their own analytics data
- Employees/admins will need separate policies to view aggregate analytics
- IP addresses are collected but can be anonymized if needed
- No personally identifiable information (PII) is stored in action logs

## Next Steps

1. **Run the SQL** to create analytics tables
2. **Update web dashboard** to include analytics.js
3. **Add tracking calls** to dashboard.js
4. **Update mobile app** to use analytics_service.dart
5. **Add tracking calls** throughout Flutter app
6. **Create admin analytics dashboard** to view metrics
7. **Set up periodic reports** (daily/weekly email summaries)

## Future Enhancements

- **Heatmaps** - Visual representation of most-clicked areas
- **Funnel analysis** - Track user flow through features
- **Cohort analysis** - Compare user groups over time
- **A/B testing** - Test different UI variations
- **Crash reporting** - Track app crashes and errors
- **Performance monitoring** - Track load times, API response times

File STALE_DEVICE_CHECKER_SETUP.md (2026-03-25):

# Stale Device Checker - Quick Start Guide

This guide will help you set up automatic device status monitoring so offline devices are detected within 60 seconds.

## What This Does

When an ESP32 device loses internet connection, the server needs to detect it and update the status:
- **0-20 seconds**: Status remains "online" (normal delay)
- **20-60 seconds**: Status changes to "stale" (connection degrading)
- **60+ seconds**: Status changes to "offline" (connection lost)

Without this checker running, devices stay showing "online" forever (like what happened on March 17).

## Quick Setup (Recommended: GitHub Actions)

This is **FREE** and requires no external services.

### Step 1: Deploy the Edge Function

```bash
# Install Supabase CLI if you haven't already
brew install supabase/tap/supabase
# OR: npm install -g supabase

# Login to Supabase
supabase login

# Link to your project (find project ref in Supabase dashboard URL)
supabase link --project-ref YOUR_PROJECT_REF

# Deploy the function
supabase functions deploy check-stale-devices
```

### Step 2: Add GitHub Secrets

1. Go to your GitHub repository
2. Click Settings → Secrets and variables → Actions
3. Add two secrets:
   - **SUPABASE_URL**: `https://nrisopysitetqycvwxsq.supabase.co` (or your URL)
   - **SUPABASE_ANON_KEY**: Your Supabase anon key (from Supabase dashboard)

### Step 3: Push to GitHub

```bash
git add .
git commit -m "Add stale device checker edge function and workflow"
git push
```

The GitHub Action will automatically start running every minute.

### Step 4: Verify It's Working

After a few minutes:

1. **Check GitHub Actions:**
   - Go to repository → Actions tab
   - See "Check Stale Devices" workflow running

2. **Check Supabase Logs:**
   ```bash
   supabase functions logs check-stale-devices
   ```

3. **Check Database:**
   ```sql
   -- See recent status changes
   SELECT
     device_id,
     status,
     started_at,
     ended_at
   FROM device_status_history
   ORDER BY started_at DESC
   LIMIT 10;
   ```

## Alternative Setup: External Cron (30-second intervals)

If you want 30-second intervals instead of 1-minute:

### Option A: cron-job.org (Free)

1. Sign up at https://cron-job.org
2. Create new cron job:
   - **Title**: Check Stale Devices
   - **URL**: `https://nrisopysitetqycvwxsq.supabase.co/functions/v1/check-stale-devices`
   - **Interval**: Every 30 seconds (or 1 minute)
   - **HTTP Method**: POST
   - **Request Headers**:
     ```
     Authorization: Bearer YOUR_ANON_KEY
     Content-Type: application/json
     ```

### Option B: EasyCron (Free)

1. Sign up at https://www.easycron.com
2. Similar setup to cron-job.org
3. Free tier allows 1-minute intervals

## Testing Locally

Before deploying, test the function locally:

```bash
# Create .env.local file
cp supabase/functions/.env.example supabase/functions/.env.local

# Edit .env.local and add your Supabase credentials
nano supabase/functions/.env.local

# Run local test
./supabase/functions/test-local.sh

# In another terminal, call the function
curl -X POST http://localhost:54321/functions/v1/check-stale-devices \
  -H "Content-Type: application/json"
```

## Monitoring

### View Status Changes

```sql
-- Current device status
SELECT
  device_id,
  connection_status,
  seconds_since_last_data,
  last_data_received_at
FROM moveometers;

-- Recent status transitions
SELECT
  device_id,
  status,
  started_at,
  ended_at,
  ROUND(duration_seconds / 3600.0, 2) as duration_hours
FROM device_status_history
ORDER BY started_at DESC
LIMIT 20;
```

### Check Function Health

```bash
# View edge function logs
supabase functions logs check-stale-devices --tail

# Manual function call to test
curl -X POST \
  "https://nrisopysitetqycvwxsq.supabase.co/functions/v1/check-stale-devices" \
  -H "Authorization: Bearer YOUR_ANON_KEY"
```

## Cost

Both options are **FREE**:

- **GitHub Actions**: 2,000 minutes/month free (this uses ~44 minutes/month)
- **Supabase Edge Functions**: 500K invocations/month free (this uses ~43K/month)
- **cron-job.org**: Free for basic cron jobs

## Troubleshooting

### "Function not found" error

Deploy the function first:
```bash
supabase functions deploy check-stale-devices
```

### "Database function not found" error

Run the database migrations:
```bash
# Run the SQL files in database/ directory in Supabase SQL Editor
# Specifically: 13_create_stale_device_checker.sql
```

### GitHub Action not running

1. Check repository has Actions enabled (Settings → Actions)
2. Verify secrets are set correctly
3. Check Actions tab for error logs

### No status changes showing

1. Verify devices have sent data: `SELECT device_id, last_data_received_at FROM moveometers;`
2. Manually run the function: `SELECT * FROM check_stale_devices();`
3. Check edge function logs for errors

## What's Next

Once this is running:
- ✅ Devices will automatically show "offline" within 60 seconds of losing connection
- ✅ Status history will track all connection state changes
- ✅ Your dashboard and mobile app will show accurate real-time status
- ✅ No more devices stuck showing "online" for days!

For more details, see `supabase/functions/SETUP.md`

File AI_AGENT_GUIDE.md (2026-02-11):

# AI Agent Guide - moveOmeter Project

**Purpose:** This file helps AI coding assistants (Claude, GPT, Copilot, etc.) quickly understand the moveOmeter project structure, context, and how to contribute effectively.

**Last Updated:** February 10, 2026

---

## Quick Context for AI Agents

### Project Summary (30-second brief)
moveOmeter is an IoT elderly monitoring system using **ESP32-C6 + mmWave radar sensor** to track activity, sleep, and vital signs. Data uploads to **Supabase (PostgreSQL)** via WiFi every 20 seconds. A **real-time web dashboard** displays charts using Chart.js. The system supports **multi-role access** (admin/employee/caretaker/resident) with Row Level Security. Current status: **core features complete, in testing/optimization phase**.

### Technology Stack at a Glance
- **Hardware:** ESP32-C6 Feather + DFRobot SEN0623 mmWave sensor
- **Firmware:** Arduino C++ (ESPSupabase library, OTA updates enabled)
- **Backend:** Supabase (PostgreSQL + Auth + Storage + Realtime)
- **Frontend:** Vanilla JavaScript + Chart.js (no framework)
- **Deployment:** Digital Ocean Ubuntu 22.04 + Nginx at http://167.71.107.200

### Project Structure
```
moveOmeter/
├── README.md                    # Main overview and quick start
├── PROJECT_STATUS.md            # Complete current status (READ THIS FIRST)
├── ROADMAP.md                   # 6-12 month development plan
├── AI_AGENT_GUIDE.md           # This file
│
├── pictureFrame/software/
│   └── mmWave_Supabase_collector/  # ESP32-C6 Arduino firmware
│       ├── mmWave_Supabase_collector.ino  # Main firmware file
│       └── config.h                       # WiFi/Supabase credentials
│
├── web/dashboard/
│   ├── index.html              # Main dashboard page
│   ├── login.html              # Authentication page
│   ├── admin.html              # Admin panel
│   ├── dashboard.js            # Chart logic and data handling
│   ├── auth.js                 # Authentication functions
│   ├── auth-guard.js           # Route protection
│   └── config.js               # Supabase connection config
│
├── database/                    # SQL migration scripts
│   ├── setup_authentication.sql
│   ├── setup_data_access_rls.sql
│   └── run_all_migrations.sql
│
└── deployment/
    ├── deploy.sh               # Deployment script
    └── README.md               # Deployment instructions
```

---

## Understanding the Project Workflow

### Data Flow (How Everything Connects)

1. **Device → Cloud (Every 20 seconds)**
   ```
   ESP32-C6 queries mmWave sensor via UART (9600 baud)
   → Parses 40+ data fields into JSON
   → Uploads to Supabase via WiFi (ESPSupabase library)
   → Records inserted into mmwave_sensor_data table
   → device_timestamp set by ESP32-C6, created_at set by server
   ```

2. **Cloud → Dashboard (Real-time)**
   ```
   Browser opens dashboard (index.html)
   → Authenticates with Supabase Auth (if logged in)
   → Subscribes to mmwave_sensor_data table (Realtime WebSocket)
   → New data arrives → event fired
   → dashboard.js updates charts instantly
   → No polling, no page refresh needed
   ```

3. **Configuration Sync (Every 60 seconds)**
   ```
   ESP32-C6 queries moveometers table for its config
   → Checks data_collection_mode ('quick' or 'medium')
   → Adjusts sensor queries accordingly
   → Checks ota_check_interval_ms and firmware_updates table
   ```

### User Roles & Permissions (RLS)

**Role Hierarchy:**
```
admin (highest privileges)
├── Can view/edit all devices and users
├── Access to admin panel
└── Can grant/revoke permissions

employee
├── Can view all devices
├── Access to admin panel (limited)
└── Cannot manage users

caretaker
├── Can only view assigned devices (via device_access table)
├── No admin panel access
└── Read-only for their devices

caretakee (resident)
├── Can only view their own device (via caretakee_devices table)
├── No admin panel access
└── Read-only
```

**How RLS Works:**
- Queries automatically filtered by `auth.uid()` (current user's ID)
- Admins/employees: join on `user_profiles` where `role IN ('admin', 'employee')`
- Caretakers: join on `device_access` table where `user_id = auth.uid()`
- Caretakees: join on `caretakee_devices` table where `caretakee_id = auth.uid()`

---

## Key Implementation Details AI Should Know

### 1. Timeline Data Aggregation (Performance Critical)

**Problem Solved:** Rendering 1000+ data points caused browser lag.

**Solution:** Time-based bucketing
- **1-hour timeline:** No aggregation (raw data, max 180 points)
- **12-hour timeline:** 5-minute buckets (~144 points, was 2160)
- **24-hour timeline:** 10-minute buckets (~144 points, was 4320)

**Aggregation Logic:**
```javascript
function aggregateDataByTime(rawData, bucketSizeMs) {
  const buckets = new Map();

  rawData.forEach(point => {
    const timestamp = new Date(point.device_timestamp || point.created_at);
    const bucketKey = Math.floor(timestamp.getTime() / bucketSizeMs) * bucketSizeMs;

    if (!buckets.has(bucketKey)) buckets.set(bucketKey, []);
    buckets.get(bucketKey).push(point);
  });

  return Array.from(buckets.entries()).map(([bucketKey, points]) => ({
    timestamp: new Date(bucketKey),
    human_existence: Math.max(...points.map(p => p.human_existence || 0)), // MAX
    motion_detected: Math.max(...points.map(p => p.motion_detected || 0)),  // MAX
    body_movement: Math.round(points.reduce((sum, p) => sum + (p.body_movement || 0), 0) / points.length) // AVERAGE
  }));
}
```

**Why MAX for existence/motion?** Don't want to miss any activity.
**Why AVERAGE for body_movement?** Smooths out spikes, shows general trend.

---

### 2. Query Ordering Fix (Critical Bug Fixed)

**Previous Bug:**
```javascript
// WRONG - Gets oldest 1000 records
.order('device_timestamp', { ascending: true })
.limit(1000)
// Result: Data from midnight to 1 AM only (oldest data)
```

**Current Fix:**
```javascript
// CORRECT - Gets newest 1000 records, then reverses
.order('device_timestamp', { ascending: false })
.limit(10000) // Increased limit
// Then: data.reverse() to get chronological order
```

**AI Agent Note:** Always query descending and reverse, especially for time series data with limits.

---

### 3. Smart Keep-Alive Optimization

**Problem:** Uploading full sensor data every 20s wastes bandwidth when room is empty.

**Solution:**
```cpp
// In Arduino firmware:
uint16_t movement = sensor.smHumanData(eHumanMovingRange);
uint16_t humanPresence = sensor.smHumanData(eHumanPresence);
bool hasActivity = (movement > 0 || humanPresence > 0);

if (!hasActivity) {
  // Send minimal keep-alive every 30 seconds
  if (currentTime - lastKeepAliveTime >= 30000) {
    uint8_t fallState = sensor.getFallData(eFallState); // Safety check
    json = "{\"data_type\":\"keep_alive\",\"body_movement\":0,\"human_existence\":0,\"fall_state\":" + String(fallState) + "}";
    uploadData(json);
    lastKeepAliveTime = currentTime;
  }
  return; // Don't collect full data
}

// Full data collection when activity detected
```

**Result:** 97% bandwidth reduction during idle periods, while still monitoring for falls.

---

### 4. Device Timestamp vs Server Timestamp

**Important:** Use `device_timestamp` for time series queries, not `created_at`.

**Why?**
- `created_at`: When Supabase received the data (may be delayed by network)
- `device_timestamp`: When ESP32-C6 recorded the data (accurate to milliseconds)

**Usage:**
```javascript
// CORRECT
.gte('device_timestamp', startTime)
.lte('device_timestamp', endTime)
.not('device_timestamp', 'is', null) // Filter out NULL
.order('device_timestamp', { ascending: false })

// WRONG
.gte('created_at', startTime) // Don't use for timelines
```

**Edge Case:** Some old data may have `device_timestamp = NULL`. Filter it out.

---

### 5. OTA Firmware Update Process

**Status:** Infrastructure complete, needs end-to-end testing.

**How It Works:**
1. Admin uploads new firmware .bin to Supabase Storage
2. Admin creates record in `firmware_updates` table:
   ```sql
   INSERT INTO firmware_updates (version, device_model, download_url, md5_checksum, mandatory)
   VALUES ('1.0.1', 'ESP32C6_MOVEOMETER', 'https://...', 'abc123...', false);
   ```
3. ESP32-C6 checks every hour (configurable via `ota_check_interval_ms`)
4. Compares current version with latest in database
5. If newer version exists:
   - Downloads .bin file over HTTPS
   - Verifies MD5 checksum
   - Flashes to OTA partition
   - Reboots into new firmware
   - Auto-rollback if boot fails

**Partition Scheme Required:** "Minimal SPIFFS (1.9MB APP with OTA/190KB SPIFFS)"

**Testing Guide:** See `/database/OTA_QUICK_TEST.md`

---

## Common Patterns & Best Practices

### 1. Querying Supabase from Dashboard

**Standard Pattern:**
```javascript
async function fetchData() {
  try {
    const { data, error } = await db
      .from('table_name')
      .select('columns')
      .eq('device_id', deviceId) // Always filter by device
      .order('device_timestamp', { ascending: false })
      .limit(1000);

    if (error) throw error;

    // Success
    return data.reverse(); // Chronological order
  } catch (error) {
    console.error('Error fetching data:', error);
    showUserMessage('Failed to load data. Please refresh.', 'error');
    return [];
  }
}
```

**Always:**
- Check for `error` in response
- Handle errors gracefully with user-friendly messages
- Filter by `device_id` unless admin viewing all
- Use try-catch for network errors
- Return empty array on error (don't crash UI)

---

### 2. Adding New Sensor Fields

**To add a new sensor metric (e.g., "ambient_temperature"):**

1. **Update Database Schema:**
   ```sql
   ALTER TABLE mmwave_sensor_data
   ADD COLUMN ambient_temperature INTEGER;
   ```

2. **Update Arduino Firmware:**
   ```cpp
   // In collectAndUploadMediumData():
   uint16_t temp = sensor.getTemperature(); // Or appropriate function
   json += ",\"ambient_temperature\":" + String(temp);
   ```

3. **Update Dashboard (if displaying):**
   ```javascript
   // In dashboard.js, add to metric cards or chart
   const temp = latestData.ambient_temperature;
   document.getElementById('temp-value').textContent = temp + '°C';
   ```

4. **Update Documentation:**
   - Add to sensor field list in README.md
   - Document range and units
   - Update PROJECT_STATUS.md if significant feature

---

### 3. Handling Real-Time Subscriptions

**Pattern:**
```javascript
// Subscribe to new data
const subscription = db
  .channel('sensor-data')
  .on('postgres_changes',
    {
      event: 'INSERT',
      schema: 'public',
      table: 'mmwave_sensor_data',
      filter: `device_id=eq.${deviceId}` // Filter server-side
    },
    (payload) => {
      const newData = payload.new;
      handleNewData(newData); // Update charts
    }
  )
  .subscribe();

// Clean up on page unload
window.addEventListener('beforeunload', () => {
  subscription.unsubscribe();
});
```

**Important:**
- Always filter subscriptions by `device_id` to reduce bandwidth
- Unsubscribe when component unmounts/page closes
- Handle connection loss gracefully (reconnect logic)

---

### 4. Role-Based UI Elements

**Pattern:**
```javascript
// In auth-guard.js or similar
const userRole = window.currentUser?.role;

// Show/hide admin button
if (['admin', 'employee'].includes(userRole)) {
  document.getElementById('admin-btn').style.display = 'block';
} else {
  document.getElementById('admin-btn').style.display = 'none';
}

// Check before admin actions
function deleteUser(userId) {
  if (userRole !== 'admin') {
    alert('Only admins can delete users');
    return;
  }
  // Proceed with deletion
}
```

**Security Note:** UI hiding is UX, not security. RLS policies enforce actual permissions.

---

## File-Specific Guidance

### Working with `mmWave_Supabase_collector.ino`

**Key Sections:**
```cpp
// 1. Configuration (lines ~20-50)
#define FIRMWARE_VERSION "1.0.0"
#define DATA_INTERVAL 20000 // milliseconds
#define KEEP_ALIVE_INTERVAL 30000

// 2. Sensor initialization (setup())
if (!sensor.begin(Serial1)) {
  USB_SERIAL.println("Sensor init failed");
  while(1); // Halt
}

// 3. WiFi connection (connectWiFi())
WiFi.begin(WIFI_SSID, WIFI_PASSWORD);
// Auto-reconnect logic included

// 4. Data collection (loop())
if (deviceConfig.dataCollectionMode == "quick") {
  collectAndUploadQuickData();
} else {
  collectAndUploadMediumData();
}

// 5. Configuration sync (fetchDeviceConfig())
// Runs every 60 seconds
// Updates deviceConfig struct from database

// 6. OTA updates (checkForFirmwareUpdate())
// Runs every ota_check_interval_ms (default 1 hour)
```

**When Modifying:**
- Always increment `FIRMWARE_VERSION` after changes
- Test with Serial Monitor at 115200 baud
- Use `USB_SERIAL.println()` for debugging (not `Serial.println()`)
- Remember partition scheme: Minimal SPIFFS (1.9MB APP with OTA)

**Common Sensor Functions:**
```cpp
// Human presence (0 or 1)
sensor.smHumanData(eHumanPresence)

// Movement range (0-100)
sensor.smHumanData(eHumanMovingRange)

// Body movement intensity (0-100)
sensor.smHumanData(eHumanMovement)

// Heart rate (BPM)
sensor.getBedData(eHeartRate)

// Respiration rate
sensor.getBedData(eBreathValue)

// Fall detection
sensor.getFallData(eFallState) // 0=no fall, 1=fall detected
```

---

### Working with `dashboard.js`

**Key Functions:**

1. **Data Loading:**
   ```javascript
   async function loadTimelineData() {
     // Loads historical data for charts
     // Called on page load and device change
   }
   ```

2. **Real-Time Updates:**
   ```javascript
   function setupRealtimeSubscription() {
     // Subscribes to new data
     // Updates charts automatically
   }
   ```

3. **Chart Updates:**
   ```javascript
   function update1HourTimeline(newData)
   function update12HourTimeline(newData) // Uses aggregation
   function update24HourTimeline(newData) // Uses aggregation
   ```

4. **Device Status:**
   ```javascript
   function checkDeviceOnlineStatus() {
     // Runs every 5 seconds
     // Shows "Online" or "Offline (X seconds ago)"
     // Hides metrics when offline
   }
   ```

**Global Variables AI Should Know:**
```javascript
const db = createClient(url, key); // Supabase client
let currentDeviceId = 'ESP32C6_001'; // Selected device
let timeline1HourBuffer = []; // Raw data for 1-hour chart
let timeline12HourBuffer = []; // Raw data for 12-hour chart
let timeline24HourBuffer = []; // Raw data for 24-hour chart
```

---

### Working with Database Migrations

**Order of Execution:**
1. `setup_authentication.sql` - Creates tables, RLS policies, triggers
2. `setup_data_access_rls.sql` - Additional RLS policies for device access
3. `create_annotations_only.sql` - Adds annotations table
4. Various `fix_*.sql` - Bug fixes and improvements

**To Add New Migration:**
1. Create new file: `database/feature_name.sql`
2. Add clear comments explaining what and why
3. Include rollback instructions (how to undo)
4. Update `run_all_migrations.sql` to include it
5. Test on dev Supabase project first
6. Document in PROJECT_STATUS.md

**Migration Template:**
```sql
-- Migration: Add feature X
-- Date: 2026-02-XX
-- Purpose: Explain why this change is needed

-- Table creation
CREATE TABLE IF NOT EXISTS table_name (
  id UUID PRIMARY KEY DEFAULT uuid_generate_v4(),
  created_at TIMESTAMPTZ DEFAULT NOW(),
  -- other fields
);

-- Indexes
CREATE INDEX idx_name ON table_name(column);

-- RLS Policies
ALTER TABLE table_name ENABLE ROW LEVEL SECURITY;

CREATE POLICY "policy_name"
ON table_name
FOR SELECT
USING (auth.uid() = user_id);

-- Triggers (if needed)
CREATE OR REPLACE FUNCTION trigger_function()
RETURNS TRIGGER AS $$
BEGIN
  -- Logic here
  RETURN NEW;
END;
$$ LANGUAGE plpgsql;

CREATE TRIGGER trigger_name
AFTER INSERT ON table_name
FOR EACH ROW
EXECUTE FUNCTION trigger_function();

-- Rollback instructions:
-- DROP TABLE table_name;
-- DROP FUNCTION trigger_function();
```

---

## Decision-Making Guidelines for AI Agents

### When to Create New Files vs Modify Existing

**Create New File When:**
- Adding entirely new feature (new page, new component)
- Creating documentation (new guide, new setup instructions)
- Adding database migration (always separate file)

**Modify Existing File When:**
- Fixing bugs in existing functionality
- Adding fields to existing forms
- Improving existing features
- Updating documentation for current features

### When to Ask User vs Decide Autonomously

**Always Ask User:**
- Breaking changes (changing function signatures, removing features)
- Database schema changes (adding/removing columns)
- Security-related changes (authentication, permissions)
- Architecture changes (switching libraries, frameworks)
- UI/UX changes that affect user workflow
- Deployment changes (server configuration, DNS)

**Decide Autonomously (with explanation):**
- Bug fixes (if root cause is clear)
- Performance optimizations (if no breaking changes)
- Code refactoring (if behavior unchanged)
- Documentation improvements
- Adding comments or logging
- Consistent styling/formatting

### Code Style Preferences

**JavaScript:**
- Use `const` and `let`, never `var`
- Use async/await, not Promise chains
- Use template literals: \`${variable}\` not `"" + variable + ""`
- Use arrow functions for callbacks
- Comment complex logic

**Arduino C++:**
- Use `USB_SERIAL.println()` not `Serial.println()`
- Always check return values (WiFi.status(), sensor.begin())
- Use `unsigned long` for timestamps (millis())
- Define constants at top of file
- Keep functions focused (single responsibility)

**SQL:**
- Use uppercase for keywords (SELECT, FROM, WHERE)
- Include IF NOT EXISTS for safety
- Comment complex queries
- Always specify schema (public.table_name)
- Include rollback instructions

**HTML/CSS:**
- Semantic HTML (use `<section>`, `<article>`, not just `<div>`)
- Responsive design (mobile-first)
- Accessibility (ARIA labels, alt text)
- Consistent naming (kebab-case for classes)

---

## Testing Guidelines

### How to Verify Changes Work

**Firmware Changes:**
1. Compile in Arduino IDE (verify no errors)
2. Upload to ESP32-C6
3. Open Serial Monitor (115200 baud)
4. Look for success messages:
   ```
   WiFi connected
   Supabase initialized
   Data uploaded: SUCCESS!
   ```
5. Check Supabase table for new data
6. Verify dashboard displays new data

**Dashboard Changes:**
1. Open browser Developer Tools (F12)
2. Check Console for errors
3. Check Network tab for failed requests
4. Test with hard refresh (Ctrl+Shift+R)
5. Test in incognito/private window (cache bypass)
6. Test on different browser (Chrome, Firefox, Safari)

**Database Changes:**
1. Run migration on test project first
2. Verify tables created: `\dt` in SQL editor
3. Test INSERT/SELECT queries
4. Verify RLS policies work (test as different roles)
5. Check triggers fire correctly
6. Backup before running on production

### Common Issues & How to Debug

**Issue: Dashboard shows "Disconnected"**
```
Debug steps:
1. Check browser console for errors
2. Verify config.js has correct Supabase URL/key
3. Test Supabase connection:
   const { data } = await db.from('moveometers').select().limit(1)
   console.log(data)
4. Check Supabase dashboard → Logs for errors
```

**Issue: Firmware won't compile**
```
Debug steps:
1. Verify libraries installed (ESPSupabase, DFRobot_HumanDetection)
2. Check board selected: ESP32C6 Dev Module
3. Check partition: Minimal SPIFFS (1.9MB APP with OTA)
4. Read error message carefully (line number, missing function)
5. Check for typos in function names (case-sensitive)
```

**Issue: Data not appearing in database**
```
Debug steps:
1. Check Serial Monitor for upload status
2. Look for "SUCCESS!" message
3. If "FAILED", check error code (401, 404, 500)
4. 401 = wrong API key
5. 404 = table doesn't exist or wrong name
6. 500 = server error (check Supabase logs)
7. Test with manual INSERT in SQL editor
```

**Issue: RLS denying access**
```
Debug steps:
1. Check which user is authenticated: auth.uid()
2. Check user's role in user_profiles
3. Review RLS policy for table:
   SELECT * FROM pg_policies WHERE tablename = 'table_name';
4. Test policy manually:
   SELECT * FROM table_name WHERE <policy condition>;
5. Temporarily disable RLS for testing:
   ALTER TABLE table_name DISABLE ROW LEVEL SECURITY;
   (Don't forget to re-enable!)
```

---

## Integration Points (How Systems Connect)

### ESP32-C6 ↔ Supabase

**Connection:**
```cpp
#include <ESPSupabase.h>

Supabase db;
db.begin(SUPABASE_URL, SUPABASE_ANON_KEY);

// Insert data
String json = "{\"device_id\":\"ESP32C6_001\",\"value\":123}";
int code = db.insert(SUPABASE_TABLE, json, false);
// code: 201 = success, 401 = unauthorized, 404 = table not found
```

**Authentication:** Uses anon key (safe for device inserts, RLS allows public insert)

---

### Dashboard ↔ Supabase

**Connection:**
```javascript
import { createClient } from 'https://cdn.jsdelivr.net/npm/@supabase/supabase-js@2/+esm'

const db = createClient(SUPABASE_CONFIG.url, SUPABASE_CONFIG.anonKey);

// Authenticated request (after login)
const { data, error } = await db.from('table').select('*');
// RLS automatically enforces permissions based on logged-in user
```

**Authentication:** Uses Supabase Auth (email/password), session stored in localStorage

---

### Real-Time Data Flow

**Sequence:**
```
1. ESP32-C6 inserts row into mmwave_sensor_data
2. Supabase broadcasts INSERT event via WebSocket
3. Dashboard receives event (if subscribed)
4. Dashboard.js calls handleNewData(payload.new)
5. Charts update with new data point
6. UI shows updated timestamp
```

**Subscription Setup:**
```javascript
db.channel('changes')
  .on('postgres_changes',
    { event: 'INSERT', schema: 'public', table: 'mmwave_sensor_data' },
    handleNewData
  )
  .subscribe()
```

---

## Scaling Considerations for AI Agents

### Current Limitations (10 devices)
- Single dashboard page (no pagination)
- No caching layer
- Direct database queries
- Real-time subscription per device

### At 100 Devices
- Need device search/filter
- Consider query result caching
- Aggregate metrics (don't load all devices at once)

### At 1,000 Devices
- Require read replicas
- Implement Redis caching
- Background jobs for analytics
- Message queue for data ingestion

### At 10,000+ Devices
- Microservices architecture
- Time-series database (TimescaleDB)
- Distributed tracing
- Edge computing (process on device)

**AI Agent Note:** When adding features, consider "will this work at 10,000 devices?" If not, document the scaling limitation.

---

## Deployment Workflow

### Local Development
```bash
# 1. Start local dashboard
cd web/dashboard
python3 -m http.server 8000

# 2. Open browser
open http://localhost:8000

# 3. Make changes to HTML/JS/CSS
# 4. Hard refresh browser (Cmd+Shift+R)

# 5. Test with Serial Monitor for firmware
# Arduino IDE → Tools → Serial Monitor (115200 baud)
```

### Deploying to Production
```bash
# From deployment directory
cd deployment
./deploy.sh deploy@167.71.107.200

# This:
# 1. Uploads files to /tmp/moveometer-deploy/
# 2. Copies to /var/www/moveometer/
# 3. Sets permissions (www-data:www-data)
# 4. Reloads Nginx
```

### Versioning Strategy
- Firmware: Increment `FIRMWARE_VERSION` in .ino file
- Dashboard: No versioning yet (TODO: add version.js)
- Database: Migration files dated and numbered

---

## Quick Reference Cheat Sheet

### Arduino Sensor Queries
| Function | Purpose | Return Type |
|---|---|---|
| `sensor.smHumanData(eHumanPresence)` | Is person present? | 0 or 1 |
| `sensor.smHumanData(eHumanMovement)` | Movement intensity | 0-100 |
| `sensor.smHumanData(eHumanMovingRange)` | Movement range | 0-100 |
| `sensor.getBedData(eHeartRate)` | Heart rate | BPM (0-255) |
| `sensor.getBedData(eBreathValue)` | Respiration | breaths/min |
| `sensor.getFallData(eFallState)` | Fall detected? | 0 or 1 |

### Supabase Table Reference
| Table | Purpose | Key Columns |
|---|---|---|
| `mmwave_sensor_data` | Time series sensor data | device_timestamp, device_id, human_existence, body_movement |
| `moveometers` | Device registry | device_id, data_collection_mode, firmware_version, ota_status |
| `user_profiles` | User accounts | id, email, role, full_name, is_active |
| `device_access` | Permissions | user_id, device_id, access_level |
| `firmware_updates` | OTA versions | version, download_url, md5_checksum |
| `audit_log` | Security events | user_id, action, success, created_at |
| `annotations` | Timeline notes | device_id, annotation_time, text, annotation_type |

### JavaScript Supabase Queries
```javascript
// Select with filter
const { data, error } = await db
  .from('table')
  .select('*')
  .eq('column', value)
  .order('created_at', { ascending: false })
  .limit(100);

// Insert
const { data, error } = await db
  .from('table')
  .insert({ column1: value1, column2: value2 });

// Update
const { data, error } = await db
  .from('table')
  .update({ column: newValue })
  .eq('id', recordId);

// Delete
const { data, error } = await db
  .from('table')
  .delete()
  .eq('id', recordId);

// Subscribe to changes
const subscription = db
  .channel('channel-name')
  .on('postgres_changes', { event: 'INSERT', schema: 'public', table: 'table_name' }, callback)
  .subscribe();
```

---

## Important Context for Specific Tasks

### If Asked to Add New Chart
1. Add `<canvas id="newChart"></canvas>` to index.html
2. Initialize Chart.js in dashboard.js:
   ```javascript
   const newChart = new Chart(document.getElementById('newChart'), {
     type: 'line',
     data: { labels: [], datasets: [{ label: 'Metric', data: [] }] },
     options: { responsive: true }
   });
   ```
3. Update chart in real-time handler:
   ```javascript
   function updateNewChart(newData) {
     newChart.data.labels.push(newData.timestamp);
     newChart.data.datasets[0].data.push(newData.value);
     newChart.update();
   }
   ```

### If Asked to Add New User Role
1. Update `user_profiles.role` check constraint in database:
   ```sql
   ALTER TABLE user_profiles DROP CONSTRAINT IF EXISTS user_profiles_role_check;
   ALTER TABLE user_profiles ADD CONSTRAINT user_profiles_role_check
     CHECK (role IN ('admin', 'employee', 'caretaker', 'caretakee', 'new_role'));
   ```
2. Add RLS policy for new role
3. Update auth-guard.js to handle new role
4. Update UI role-based visibility logic
5. Document in AUTH_SETUP.md

### If Asked to Add New Sensor Metric
See "Adding New Sensor Fields" section above.

### If Asked to Optimize Performance
1. Check current bottleneck (use browser Performance tab)
2. Common optimizations:
   - Data aggregation (already implemented for timelines)
   - Lazy loading (load data only when needed)
   - Virtual scrolling (for long lists)
   - Debouncing (for frequent events)
   - Caching (localStorage for static data)
   - Minification (use build tool)
3. Document before/after metrics

---

## Glossary of Project-Specific Terms

- **mmWave:** Millimeter wave radar technology (privacy-preserving, no camera)
- **SEN0623:** DFRobot mmWave sensor model number
- **ESP32-C6:** Microcontroller with WiFi and Bluetooth
- **Supabase:** Backend-as-a-Service (PostgreSQL + Auth + Storage + Realtime)
- **RLS:** Row Level Security (PostgreSQL feature for data isolation)
- **OTA:** Over-The-Air firmware updates
- **Keep-alive:** Minimal data upload when no activity (bandwidth optimization)
- **Device timestamp:** When ESP32-C6 recorded data (accurate for time series)
- **Created timestamp:** When Supabase received data (may be delayed)
- **Quick mode:** Minimal sensor queries (battery saver)
- **Medium mode:** Full sensor suite (when presence detected)
- **Annotation:** User-added note on timeline
- **Aggregation:** Grouping data into time buckets (performance optimization)

---

## Final Notes for AI Agents

**Philosophy:**
- Privacy-first (no cameras, no wearables)
- Simple before complex (vanilla JS before framework)
- User-friendly (non-technical caregivers)
- Scalable (design for millions, build for hundreds)
- Secure (RLS, authentication, audit logging)

**When in Doubt:**
1. Read PROJECT_STATUS.md for current state
2. Check ROADMAP.md for planned direction
3. Review relevant documentation in /database/ or /web/
4. Ask user if decision has long-term implications

**Success Criteria:**
- Code works on first try (test before suggesting)
- Changes don't break existing features (test regression)
- Performance is maintained or improved
- Security is maintained or improved
- Documentation is updated

**AI Agent Motto:** "Make it work, make it right, make it fast, make it documented."

---

**This guide will be updated as the project evolves. Last updated: February 10, 2026**

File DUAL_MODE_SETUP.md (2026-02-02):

# moveOmeter Dual Mode Setup Guide

Complete guide for running Sleep Mode and Fall Detection Mode devices with the unified dashboard.

## 🎯 Overview

Your moveOmeter system now supports **two monitoring modes**:

1. **Sleep Mode** (🛏️) - Comprehensive health monitoring, sleep analysis, vital signs
2. **Fall Detection** (🚨) - Fall detection, position tracking, residency monitoring

## 📋 Setup Steps

### Step 1: Update Supabase Database

Run this SQL in your Supabase SQL Editor to add fall detection fields:

```sql
-- Located in: database/add_fall_detection_fields.sql
-- Copy and paste the contents into Supabase SQL Editor and run
```

Or directly:
```bash
cat /Users/johnreine/Dropbox/john/2025_work/moveOmeter/database/add_fall_detection_fields.sql
```

This adds:
- `sensor_mode` column (to distinguish between modes)
- All fall detection data fields
- Indexes for performance

### Step 2: Deploy Sleep Mode Device (Bedroom)

**Location:** `pictureFrame/software/mmWave_Supabase_collector/`

1. Open `config.h` and set:
   ```cpp
   #define DEVICE_ID "bedroom_device"
   #define LOCATION "bedroom_1"
   ```

2. Upload to ESP32-C6
3. Verify data appears in Supabase with `sensor_mode = 'sleep'`

### Step 3: Deploy Fall Detection Device (Bathroom/Hallway)

**Location:** `pictureFrame/software/mmWave_FallDetection_collector/`

1. Copy and edit `config.h`:
   ```cpp
   #define WIFI_SSID "your_wifi"
   #define WIFI_PASSWORD "your_password"
   #define SUPABASE_URL "your_url"
   #define SUPABASE_ANON_KEY "your_key"
   #define SUPABASE_TABLE "mmwave_sensor_data"
   #define DEVICE_ID "bathroom_device"
   #define LOCATION "bathroom_1"
   ```

2. Upload to a second ESP32-C6
3. Verify data appears with `sensor_mode = 'fall_detection'`

### Step 4: Use the Dashboard

**Location:** `web/dashboard/`

1. Start the dashboard:
   ```bash
   cd /Users/johnreine/Dropbox/john/2025_work/moveOmeter/web/dashboard
   ./start_dashboard.sh
   ```

2. Open: http://localhost:8000

3. **Switch between modes** using the toggle at the top:
   - 🛏️ **Sleep Mode** - Shows bedroom device data
   - 🚨 **Fall Detection** - Shows bathroom device data

## 📊 Dashboard Features

### Sleep Mode View
**Metrics:**
- Heart Rate
- Respiration Rate
- Presence Detection
- In Bed Status
- Sleep Quality Score
- Apnea Events

**Charts:**
- Heart Rate over time
- Respiration Rate over time
- Presence & Movement tracking
- Sleep Quality trends

**Alerts:**
- Apnea events
- Abnormal struggle
- Out of bed during night hours
- Unattended state

### Fall Detection View
**Metrics:**
- Fall Detected (YES/NO)
- Person Present
- Motion Detected
- Position X/Y coordinates
- Time on Floor

**Charts:**
- Fall Events timeline
- Movement tracking (existence + motion)
- Position Map (scatter plot of X/Y coordinates)
- Static Residency Time

**Alerts:**
- 🚨 Fall detected
- Person on floor > 30 seconds
- Fall duration warnings

## 🏠 Recommended Deployment

### Single Room (Start Here)
- **1 device in bedroom** - Sleep Mode
- Monitor sleep quality, vital signs, and general well-being

### Two Room Setup
- **Bedroom** - Sleep Mode device
- **Bathroom** - Fall Detection device
- High-risk areas covered

### Complete Home Coverage
- **Bedroom** - Sleep Mode
- **Bathroom** - Fall Detection
- **Hallway** - Fall Detection
- **Living Room** - Sleep Mode

Each device sends data to the same Supabase table with:
- Unique `device_id`
- Unique `location`
- Appropriate `sensor_mode`

## 🔧 Configuration

### Device Config (`config.h`)
```cpp
#define DEVICE_ID "unique_name"      // Make unique per device
#define LOCATION "room_name"          // Bedroom, bathroom, etc.
#define DATA_INTERVAL 5000            // Data collection frequency (ms)
```

### Dashboard Config (`config.js`)
```javascript
deviceId: null,  // Set to null to see ALL devices, or specific ID to filter
refreshInterval: 5000,
maxDataPoints: 20
```

## 📱 Multi-Device Monitoring

To see all devices at once:

1. Edit `web/dashboard/config.js`:
   ```javascript
   deviceId: null  // Show data from all devices
   ```

2. Switch between Sleep and Fall Detection modes to see:
   - **Sleep Mode**: All bedroom/living room devices
   - **Fall Detection**: All bathroom/hallway devices

Or create multiple browser tabs, each filtered to a specific device!

## 🚨 Alert System

### Sleep Mode Alerts
- **Critical:** Apnea events, abnormal struggle
- **Warning:** Out of bed during night hours
- **Info:** Unattended state

### Fall Detection Alerts
- **Critical:** Fall detected, person on floor > 30 sec
- **Warning:** Extended fall duration
- **Info:** Static residency detected

All alerts appear in red banner at top of dashboard.

## 📊 Data Storage

Both modes store data in the same table:
```
mmwave_sensor_data
├── sensor_mode: 'sleep' or 'fall_detection'
├── device_id: unique device identifier
├── location: room/area name
├── created_at: timestamp
├── [sleep mode fields...]
└── [fall detection fields...]
```

**Storage Optimization:**
- Sleep mode fields are NULL for fall detection records
- Fall detection fields are NULL for sleep mode records
- Only relevant fields populated per mode

## 🎨 Customization

### Change Device to Different Mode

Sleep → Fall Detection:
1. Open the Arduino sketch
2. Change line 70:
   ```cpp
   sensor.configWorkMode(DFRobot_HumanDetection::eFallingMode);
   ```
3. Re-upload firmware

Fall Detection → Sleep:
1. Change to:
   ```cpp
   sensor.configWorkMode(DFRobot_HumanDetection::eSleepMode);
   ```
2. Re-upload firmware

### Add More Devices

1. Clone firmware folder
2. Edit `config.h` with unique `DEVICE_ID` and `LOCATION`
3. Upload to new ESP32-C6
4. Data automatically appears in dashboard

## 🔍 Troubleshooting

### Dashboard shows no data after mode switch
- Wait 5 seconds for new data to arrive
- Check that you have devices running in the selected mode
- Verify `sensor_mode` field in Supabase matches the mode

### Fall detection metrics show "--"
- Ensure you uploaded the Fall Detection firmware (not Sleep Mode)
- Check Serial Monitor for "Fall Detection Mode" confirmation
- Verify database has `sensor_mode = 'fall_detection'` records

### Both modes show same data
- Check `sensor_mode` field in database
- Ensure different devices are using different firmware
- Clear browser cache and refresh

## 📈 Next Steps

1. **Deploy multiple devices** across different rooms
2. **Set up notifications** for critical alerts (SMS/email via Supabase Edge Functions)
3. **Create location-based dashboards** for each room
4. **Build mobile app** for caregivers (iOS/Android)
5. **Add historical analysis** (daily/weekly/monthly reports)

## 📁 File Locations

```
moveOmeter/
├── pictureFrame/software/
│   ├── mmWave_Supabase_collector/        # Sleep Mode firmware
│   └── mmWave_FallDetection_collector/   # Fall Detection firmware
├── web/dashboard/                         # Unified dashboard
├── database/
│   └── add_fall_detection_fields.sql     # Database migration
└── DUAL_MODE_SETUP.md                    # This file
```

## 🎯 Success Checklist

- ✅ Database updated with fall detection fields
- ✅ Sleep Mode device deployed and uploading data
- ✅ Fall Detection device deployed and uploading data
- ✅ Dashboard showing data in both modes
- ✅ Mode toggle working correctly
- ✅ Alerts appearing for each mode
- ✅ Real-time updates working

You now have a complete dual-mode elderly monitoring system! 🎉

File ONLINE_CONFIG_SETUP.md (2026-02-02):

# Online Configuration System Setup

## Overview

The moveOmeter now fetches all configuration settings from Supabase, allowing you to manage devices remotely without re-uploading firmware. Settings are automatically synchronized every 10 minutes.

---

## 🗄️ Database Setup

### Step 1: Create Tables

Run the SQL script in Supabase SQL Editor:

```bash
cat database/create_moveometer_tables.sql
```

This creates:
- **moveometer_models** - Device model definitions
- **moveometers** - Individual device configurations
- **moveometer_config_history** - Configuration change tracking

### Step 2: Verify Sample Data

Your device `ESP32C6_001` should already be in the `moveometers` table with default settings:

```sql
SELECT device_id, operational_mode, data_interval_ms, install_height_cm, device_status
FROM moveometers
WHERE device_id = 'ESP32C6_001';
```

---

## 📋 Configuration Fields

### Device Identification
- `device_id` - Unique identifier (e.g., "ESP32C6_001")
- `serial_number` - Manufacturing serial number
- `mac_address` - Device MAC address
- `location_name` - Physical location (e.g., "bedroom_1")

### Operational Settings
- **`operational_mode`** - `"sleep"` or `"fall_detection"` ⭐
- **`data_interval_ms`** - Milliseconds between readings (default: 1000)
- `device_status` - "active", "inactive", "error", "maintenance"

### Fall Detection Mode Settings
- `fall_sensitivity` - Sensitivity level 1-9 (default: 5)
- `fall_break_height_cm` - Height threshold for falls (default: 100)
- `install_height_cm` - Sensor mounting height (default: 250)
- `install_angle` - Sensor tilt angle in degrees (default: 0)

### Sleep Monitoring Mode Settings
- `sleep_detection_distance_cm` - Max distance for sleep detection (default: 250)
- `breathing_alert_min` - Alert if breathing < this (default: 10)
- `breathing_alert_max` - Alert if breathing > this (default: 25)
- `heart_rate_alert_min` - Min heart rate alert (default: 60)
- `heart_rate_alert_max` - Max heart rate alert (default: 100)
- `apnea_alert_threshold` - Number of apnea events to trigger alert (default: 3)

### Position Tracking
- `position_tracking_enabled` - Enable/disable position tracking (default: true)
- `track_frequency_hz` - Tracking update frequency (default: 1)
- `room_width_ft` - Room width in feet (default: 15.0)
- `room_length_ft` - Room length in feet (default: 20.0)

### Network Settings
- `wifi_ssid` - WiFi network name
- `wifi_password_encrypted` - Encrypted WiFi password
- `mqtt_broker` - MQTT broker address (future use)

---

## 🔧 How It Works

### On Device Boot:
1. ESP32 connects to WiFi
2. Fetches configuration from `moveometers` table by `device_id`
3. Applies settings to mmWave sensor
4. Begins data collection

### During Operation:
- Checks for config updates every **10 minutes**
- Applies any changes automatically
- Logs configuration changes to `moveometer_config_history`

### Configuration Flow:
```
Supabase moveometers table
        ↓
   [Arduino Firmware]
        ↓
   mmWave Sensor
        ↓
   Supabase sensor_data table
```

---

## 🎮 Changing Configuration

### Switch Between Sleep and Fall Detection Modes

**Option 1: Via Supabase Dashboard**
```sql
UPDATE moveometers
SET operational_mode = 'sleep'  -- or 'fall_detection'
WHERE device_id = 'ESP32C6_001';
```

**Option 2: Via Web UI** (future feature)
- Dashboard settings page
- Click "Switch Mode" button
- Changes take effect within 10 minutes

### Change Data Collection Rate

```sql
-- Faster sampling (500ms = 2Hz)
UPDATE moveometers
SET data_interval_ms = 500
WHERE device_id = 'ESP32C6_001';

-- Slower sampling (2 seconds = 0.5Hz)
UPDATE moveometers
SET data_interval_ms = 2000
WHERE device_id = 'ESP32C6_001';
```

### Adjust Installation Height

```sql
UPDATE moveometers
SET install_height_cm = 300  -- 3 meters
WHERE device_id = 'ESP32C6_001';
```

### Change Fall Sensitivity

```sql
-- More sensitive (detects smaller falls)
UPDATE moveometers
SET fall_sensitivity = 8
WHERE device_id = 'ESP32C6_001';

-- Less sensitive (only detects major falls)
UPDATE moveometers
SET fall_sensitivity = 3
WHERE device_id = 'ESP32C6_001';
```

---

## 📊 Monitor Configuration Changes

View configuration history:

```sql
SELECT
    change_timestamp,
    field_changed,
    old_value,
    new_value,
    change_reason
FROM moveometer_config_history
WHERE device_id = (SELECT id FROM moveometers WHERE device_id = 'ESP32C6_001')
ORDER BY change_timestamp DESC
LIMIT 10;
```

---

## 🚀 Firmware Upload

### Step 1: Update Config (if needed)

Edit `config.h` to ensure `DEVICE_ID` matches your database entry:

```cpp
#define DEVICE_ID "ESP32C6_001"
```

### Step 2: Upload Firmware

1. Open Arduino IDE
2. Load `mmWave_Supabase_collector.ino`
3. Upload to ESP32-C6
4. Open Serial Monitor (115200 baud)

### Step 3: Verify Configuration Fetch

You should see:

```
=================================
mmWave Supabase Data Collector
=================================
Connecting to WiFi: Pleasevote... CONNECTED!
Syncing time with NTP servers... SUCCESS!
Initializing Supabase... SUCCESS!
Initializing sensor... SUCCESS!
Sensor initialized! Fetching config...

Fetching device config from database... SUCCESS!
Config received:
{...}
  Mode: fall_detection
  Data Interval: 1000 ms
  Install Height: 250 cm
  Fall Sensitivity: 5
  Position Tracking: Enabled

Applying configuration to sensor...
  Configuring FALL DETECTION MODE... SUCCESS!
  Setting fall sensitivity to 5... DONE!
  Setting installation height to 250 cm... DONE!
Configuration applied successfully!

=================================
Monitoring active!
Calibrating sensor (wait 30-60 seconds)...
```

---

## 🔄 Configuration Sync Behavior

### Automatic Updates
- Device checks for config updates **every 10 minutes**
- No firmware upload needed for config changes
- Changes apply immediately after sync

### Force Immediate Update
Restart the device:
1. Press reset button on ESP32-C6, or
2. Power cycle the device

### What Triggers Config Fetch?
- Device boot/restart
- Every 10 minutes during operation
- After WiFi reconnection (optional future feature)

---

## 🏢 Multi-Device Management

### Add Multiple Devices

```sql
INSERT INTO moveometers (
    device_id,
    serial_number,
    location_name,
    operational_mode,
    data_interval_ms,
    install_height_cm,
    device_status
) VALUES
    ('ESP32C6_002', 'SN-20260202-002', 'bathroom', 'fall_detection', 1000, 250, 'active'),
    ('ESP32C6_003', 'SN-20260202-003', 'living_room', 'sleep', 1000, 250, 'active'),
    ('ESP32C6_004', 'SN-20260202-004', 'bedroom_2', 'fall_detection', 500, 280, 'active');
```

### View All Active Devices

```sql
SELECT * FROM active_moveometers;
```

### Bulk Configuration Changes

```sql
-- Set all devices to 1-second intervals
UPDATE moveometers
SET data_interval_ms = 1000
WHERE device_status = 'active';

-- Set all bedroom devices to sleep mode
UPDATE moveometers
SET operational_mode = 'sleep'
WHERE location_name LIKE 'bedroom%';
```

---

## 🔍 Troubleshooting

### Device Not Fetching Config

**Check Serial Monitor for:**
```
Fetching device config from database... FAILED or device not found in database!
Using default configuration.
```

**Solutions:**
1. Verify `device_id` exists in database:
   ```sql
   SELECT * FROM moveometers WHERE device_id = 'ESP32C6_001';
   ```
2. Check Supabase API key in `config.h`
3. Ensure WiFi is connected
4. Check Supabase Row Level Security (RLS) policies

### Config Not Applying

**Check:**
- Device hasn't fetched new config yet (wait up to 10 minutes)
- Restart device to force immediate fetch
- Check `moveometer_config_history` for logged changes

### Sensor Mode Not Switching

**Serial Monitor shows:**
```
Configuring SLEEP MODE... FAILED!
```

**Possible causes:**
- Sensor doesn't support sleep mode (check model capabilities)
- Sensor needs power cycle
- Configuration mismatch

---

## 📈 Best Practices

### Configuration Management
1. **Test changes on one device** before bulk updates
2. **Document changes** in `change_reason` field
3. **Monitor config history** regularly
4. **Set `device_status` to "maintenance"** before major changes

### Data Collection
- **Fall detection**: 1000ms (1 Hz) is optimal
- **Sleep monitoring**: 1000-5000ms range is acceptable
- **Position tracking**: Requires ≤1000ms for smooth trails

### Security
- **Encrypt WiFi passwords** before storing in database
- **Use RLS policies** to restrict device access
- **Rotate API keys** periodically

---

## 🎯 Examples

### Example 1: Bedroom Sleep Monitor

```sql
UPDATE moveometers SET
    operational_mode = 'sleep',
    data_interval_ms = 2000,
    install_height_cm = 250,
    breathing_alert_min = 10,
    breathing_alert_max = 25,
    apnea_alert_threshold = 3
WHERE device_id = 'ESP32C6_001';
```

### Example 2: Bathroom Fall Detection

```sql
UPDATE moveometers SET
    operational_mode = 'fall_detection',
    data_interval_ms = 1000,
    install_height_cm = 240,
    fall_sensitivity = 7,  -- More sensitive for elderly
    position_tracking_enabled = true
WHERE device_id = 'ESP32C6_002';
```

### Example 3: Living Room Activity Monitor

```sql
UPDATE moveometers SET
    operational_mode = 'fall_detection',
    data_interval_ms = 500,  -- Faster for position tracking
    install_height_cm = 300,
    fall_sensitivity = 5,
    room_width_ft = 20.0,
    room_length_ft = 25.0
WHERE device_id = 'ESP32C6_003';
```

---

## 🔮 Future Enhancements

- [ ] Web UI for configuration management
- [ ] Mobile app configuration control
- [ ] Bulk device configuration templates
- [ ] Configuration scheduling (time-based mode switching)
- [ ] Remote firmware updates
- [ ] Configuration validation and rollback
- [ ] Device grouping and profiles

---

## 📁 File Locations

- **Database Schema**: `database/create_moveometer_tables.sql`
- **Firmware**: `pictureFrame/software/mmWave_Supabase_collector/`
- **This Guide**: `ONLINE_CONFIG_SETUP.md`

---

**Questions?** Check the forum or GitHub issues for troubleshooting help!

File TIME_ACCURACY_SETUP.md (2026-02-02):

# Time Accuracy Setup - moveOmeter

## 🎯 Problem Solved

**Before:** Timestamps were inaccurate!
- ❌ ESP32-C6 had no real-time clock
- ❌ Used `created_at` = when Supabase **received** data (not when reading was taken)
- ❌ WiFi delays caused wrong timestamps
- ❌ 10 second WiFi lag = 10 second timestamp error!

**After:** Accurate, NTP-synced timestamps!
- ✅ ESP32-C6 syncs with NTP time servers
- ✅ `device_timestamp` = exact moment sensor reading was taken
- ✅ Auto-resyncs every 5 minutes for drift correction
- ✅ Uses 3 redundant NTP servers (pool.ntp.org, time.nist.gov, time.google.com)
- ✅ Dashboard uses device time for accurate charts

---

## 📊 Timestamp Fields Explained

Your Supabase table now has **TWO timestamps**:

### 1. `device_timestamp` (NEW - Use This!)
**What it is:** Exact time the sensor reading was taken (from device's NTP-synced clock)

**Format:** ISO 8601 with timezone
```
2026-02-02T14:32:15-08:00
```

**Accuracy:** ±50ms (NTP sync)

**Use for:**
- ✅ Charts and graphs
- ✅ Data analysis
- ✅ Event timelines
- ✅ "What time did person enter bathroom?"

### 2. `created_at` (Keep for Debugging)
**What it is:** When Supabase server received the data

**Use for:**
- Debugging upload delays
- Detecting WiFi issues
- Network performance monitoring

**Example comparison:**
```sql
SELECT
    device_timestamp,      -- 14:32:15 (reading taken)
    created_at,            -- 14:32:17 (received 2 seconds later)
    created_at - device_timestamp as delay
FROM mmwave_sensor_data;
```

---

## 🚀 Setup Steps

### Step 1: Update Database (Required)

Run this SQL in Supabase:
```bash
cat /Users/johnreine/Dropbox/john/2025_work/moveOmeter/database/add_device_timestamp.sql
```

Or copy/paste into Supabase SQL Editor.

**What it does:**
- Adds `device_timestamp` column
- Creates indexes for performance
- Creates debugging view to compare timestamps

### Step 2: Timezone Configuration

**No configuration needed!** ✅

All timestamps are stored in **UTC** (Universal Time):
- Arduino records time in UTC
- Supabase stores in UTC
- Web UI automatically converts to **your local time**

**Benefits:**
- ✅ Works anywhere in the world
- ✅ No DST confusion
- ✅ Multiple devices in different timezones = no problem
- ✅ Standard database practice

### Step 3: Upload Updated Firmware

1. Open Arduino IDE
2. Load `mmWave_Supabase_collector.ino`
3. Upload to ESP32-C6
4. Open Serial Monitor

**You should see:**
```
Syncing time with NTP servers... SUCCESS!
Current time: 2026-02-02 14:32:15
```

### Step 4: Verify Time Accuracy

**Check Serial Monitor output:**
```json
{
  "device_timestamp": "2026-02-02T14:32:15-08:00",
  ...
}
```

**Check Supabase:**
```sql
SELECT device_id, device_timestamp, created_at
FROM mmwave_sensor_data
ORDER BY created_at DESC
LIMIT 5;
```

Timestamps should look correct!

### Step 5: Refresh Dashboard

Dashboard automatically uses `device_timestamp` now. Just refresh (Cmd+Shift+R).

---

## 🔧 How NTP Time Sync Works

### On Device Boot:
1. Connect to WiFi
2. Contact NTP servers (pool.ntp.org, time.nist.gov, time.google.com)
3. Synchronize internal clock
4. Takes ~1-2 seconds

### During Operation:
- **Every 5 minutes:** Resync with NTP servers
- Corrects clock drift (ESP32 crystal can drift 1-2 seconds/day)
- Uses 3 servers for redundancy (if one is down, tries others)

### NTP Servers Used:
1. **pool.ntp.org** - Global pool of time servers
2. **time.nist.gov** - NIST (US government standard)
3. **time.google.com** - Google's public NTP

**Accuracy:** ±50 milliseconds over internet, ±1ms on local network

---

## 📈 Dashboard Updates

**Charts now use `device_timestamp`:**
- X-axis shows exact time of sensor reading
- No more timestamp delays from WiFi
- Accurate event timelines

**Fallback behavior:**
- If `device_timestamp` missing (old data), uses `created_at`
- Backward compatible with existing data

---

## 🐛 Troubleshooting

### Time shows as 1970-01-01
**Problem:** NTP sync failed

**Fix:**
1. Check WiFi connection
2. Verify NTP servers accessible:
   ```bash
   ping pool.ntp.org
   ```
3. Check firewall allows NTP (UDP port 123)
4. Try different NTP servers

### Time is wrong by hours
**Problem:** Timezone offset incorrect

**Fix:** Adjust `GMT_OFFSET_SEC` in code:
```cpp
#define GMT_OFFSET_SEC -28800  // Your offset here
```

### Time drifts over days
**Problem:** NTP resync not working

**Fix:**
- Check Serial Monitor for "Resyncing time with NTP..."
- Should happen every 5 minutes
- Increase sync frequency if needed

### Delay between device_timestamp and created_at
**Problem:** WiFi latency or buffering

**Check delay:**
```sql
SELECT
    device_id,
    EXTRACT(EPOCH FROM (created_at - device_timestamp)) as delay_seconds
FROM mmwave_sensor_data
ORDER BY created_at DESC;
```

**Normal:** 0.5-2 seconds
**High:** 5-10 seconds (check WiFi signal)
**Very high:** 30+ seconds (WiFi issues or device buffering)

---

## 🎓 Technical Details

### ISO 8601 UTC Format
```
2026-02-02T14:32:15Z
│          │        │
│          │        └─ Z = UTC (Zulu time)
│          └─ Time (HH:MM:SS)
└─ Date (YYYY-MM-DD)
```

**Why UTC?**
- Universal standard (no timezone confusion)
- Works globally (same timestamp everywhere)
- No DST issues (UTC doesn't change)
- Database best practice
- Browser automatically converts to local

**Example:**
```
Device records:  2026-02-02T22:32:15Z  (UTC)
Database stores: 2026-02-02T22:32:15Z  (UTC)
LA user sees:    2:32:15 PM PST        (Local)
NY user sees:    5:32:15 PM EST        (Local)
London sees:     10:32:15 PM GMT       (Local)
```

**Why ISO 8601?**
- Standard format
- Sortable as string
- Supabase native support
- JavaScript Date() handles it automatically

### Time Storage in PostgreSQL
```sql
device_timestamp TIMESTAMPTZ
```
- `TIMESTAMPTZ` = Timestamp with timezone
- Stored in UTC internally
- Displayed in your timezone automatically
- Handles DST transitions

### NTP Protocol
- **Accuracy:** ±50ms over internet
- **Frequency:** Every 5 minutes
- **Servers:** 3 redundant sources
- **Port:** UDP 123

---

## ✅ Benefits

1. **Accurate event timing** - Know exact moment fall occurred
2. **Reliable analytics** - Charts based on real sensor time
3. **Debug network issues** - Compare device_timestamp vs created_at
4. **Multiple devices sync** - All devices use same time source
5. **Survives WiFi delays** - Timestamp recorded before upload
6. **Clock drift correction** - Auto-resyncs every 5 minutes

---

## 📊 Example Queries

### Find delays in data upload
```sql
SELECT
    device_id,
    device_timestamp,
    created_at,
    EXTRACT(EPOCH FROM (created_at - device_timestamp)) as delay_sec
FROM mmwave_sensor_data
WHERE EXTRACT(EPOCH FROM (created_at - device_timestamp)) > 5
ORDER BY delay_sec DESC;
```

### Events in last hour (accurate)
```sql
SELECT *
FROM mmwave_sensor_data
WHERE device_timestamp > NOW() - INTERVAL '1 hour'
ORDER BY device_timestamp DESC;
```

### Time-of-day analysis
```sql
SELECT
    EXTRACT(HOUR FROM device_timestamp) as hour_of_day,
    COUNT(*) as events
FROM mmwave_sensor_data
WHERE sensor_mode = 'fall_detection'
GROUP BY hour_of_day
ORDER BY hour_of_day;
```

---

## 🎯 Summary

**You now have:**
- ✅ NTP-synced time on ESP32-C6
- ✅ Accurate `device_timestamp` field
- ✅ Auto-resync every 5 minutes
- ✅ Dashboard using device time
- ✅ Tools to debug timing issues

**Your timestamps are now accurate to ±50 milliseconds!** 🎉

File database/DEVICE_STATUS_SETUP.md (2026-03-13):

# Device Status Migration - Setup Guide

## Overview
This migration adds server-side device status tracking, eliminating the need for clients to calculate online/offline status.

## What Gets Created

1. **New columns in `moveometers` table:**
   - `connection_status` - 'online', 'stale', 'offline', 'unknown'
   - `connection_status_updated_at` - When status last changed
   - `seconds_since_last_data` - Seconds since last data received
   - `connection_quality_score` - 0-100 quality score
   - `last_data_received_at` - Most recent data timestamp

2. **New table `device_status_history`:**
   - Tracks all status changes over time
   - Used for analytics and debugging

3. **Database trigger:**
   - Automatically updates device status on every sensor data insert
   - Records status changes in history table

4. **Stale device checker function:**
   - Callable function to update devices that haven't sent data
   - Should be run every 30 seconds via scheduled job

## Installation Steps

### Step 1: Run Migrations in Supabase SQL Editor

Open Supabase SQL Editor and run each migration file in order:

1. **10_add_device_status_columns.sql**
2. **11_create_device_status_history.sql**
3. **12_create_device_status_trigger.sql**
4. **13_create_stale_device_checker.sql**
5. **14_backfill_device_status.sql**

**OR** copy/paste all the SQL from these files in order into one query.

### Step 2: Set Up Scheduled Job

You need to run `check_stale_devices()` every 30 seconds. Options:

#### Option A: Supabase Edge Function (Recommended)

Create a Supabase Edge Function that runs on a schedule:

```typescript
// supabase/functions/check-stale-devices/index.ts
import { createClient } from 'https://esm.sh/@supabase/supabase-js@2';

Deno.serve(async () => {
  const supabase = createClient(
    Deno.env.get('SUPABASE_URL') ?? '',
    Deno.env.get('SUPABASE_SERVICE_ROLE_KEY') ?? ''
  );

  const { data, error } = await supabase.rpc('check_stale_devices');

  if (error) {
    console.error('Error checking stale devices:', error);
    return new Response(JSON.stringify({ error }), { status: 500 });
  }

  console.log('Checked stale devices:', data);
  return new Response(JSON.stringify({ success: true, changes: data }), {
    headers: { 'Content-Type': 'application/json' },
  });
});
```

Then schedule it via cron (every 30 seconds):
```bash
# In your CI/CD or use a service like cron-job.org
*/30 * * * * * curl -X POST https://your-project.supabase.co/functions/v1/check-stale-devices \
  -H "Authorization: Bearer YOUR_ANON_KEY"
```

#### Option B: External Cron Service

Use a service like:
- UptimeRobot (free tier allows 5-minute intervals)
- Cron-job.org (allows custom intervals)
- GitHub Actions (scheduled workflow)

Create an API endpoint that calls the function.

#### Option C: pg_cron Extension (If Available)

If your Supabase project has pg_cron enabled:

```sql
SELECT cron.schedule(
    'check-stale-devices',
    '*/1 * * * *', -- Every minute (30s not supported by pg_cron)
    $$SELECT check_stale_devices();$$
);
```

### Step 3: Verify Installation

Run this query to check everything is working:

```sql
-- Check device status columns exist
SELECT
    device_id,
    connection_status,
    seconds_since_last_data,
    connection_quality_score,
    last_data_received_at
FROM moveometers
LIMIT 5;

-- Check status history is being recorded
SELECT
    device_id,
    status,
    started_at,
    ended_at,
    duration_seconds
FROM device_status_history
ORDER BY started_at DESC
LIMIT 10;

-- Test the stale device checker
SELECT * FROM check_stale_devices();
```

### Step 4: Test the Trigger

Insert test data and watch the status update:

```sql
-- Before: Check current status
SELECT device_id, connection_status, seconds_since_last_data
FROM moveometers
WHERE device_id = 'ESP32C6_001';

-- Insert new data
INSERT INTO mmwave_sensor_data (
    device_id,
    sensor_mode,
    device_timestamp,
    human_existence,
    body_movement
) VALUES (
    'ESP32C6_001',
    'fall_detection',
    NOW(),
    1,
    50
);

-- After: Check status updated automatically
SELECT device_id, connection_status, seconds_since_last_data
FROM moveometers
WHERE device_id = 'ESP32C6_001';

-- Check history was recorded
SELECT device_id, status, started_at, ended_at
FROM device_status_history
WHERE device_id = 'ESP32C6_001'
ORDER BY started_at DESC
LIMIT 3;
```

## Status Thresholds

- **Online**: Data received within last 20 seconds
- **Stale**: Data received 20-60 seconds ago
- **Offline**: No data for more than 60 seconds
- **Unknown**: No data ever received

## Troubleshooting

### Status not updating on data insert

1. Check trigger exists:
   ```sql
   SELECT tgname FROM pg_trigger WHERE tgname = 'trigger_update_device_status';
   ```

2. Check for errors in logs

3. Manually run the update function:
   ```sql
   SELECT update_device_status();
   ```

### Status not updating for stale devices

1. Ensure `check_stale_devices()` is being called regularly
2. Check function output:
   ```sql
   SELECT * FROM check_stale_devices();
   ```
3. Verify last_data_received_at is set:
   ```sql
   SELECT device_id, last_data_received_at FROM moveometers;
   ```

## Next Steps

After database setup is complete:
1. Test with your ESP32 device
2. Update mobile app to read status from database
3. Update web dashboard to read status from database
4. Remove all client-side status calculation logic

## Rollback

If you need to rollback these changes:

```sql
-- Drop trigger
DROP TRIGGER IF EXISTS trigger_update_device_status ON mmwave_sensor_data;

-- Drop functions
DROP FUNCTION IF EXISTS update_device_status();
DROP FUNCTION IF EXISTS check_stale_devices();

-- Drop status history table
DROP TABLE IF EXISTS device_status_history CASCADE;

-- Remove columns from moveometers
ALTER TABLE moveometers
DROP COLUMN IF EXISTS connection_status,
DROP COLUMN IF EXISTS connection_status_updated_at,
DROP COLUMN IF EXISTS seconds_since_last_data,
DROP COLUMN IF EXISTS connection_quality_score,
DROP COLUMN IF EXISTS last_data_received_at;
```

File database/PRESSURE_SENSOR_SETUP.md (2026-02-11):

# DPS310 Pressure Sensor Setup for Door Detection

## Hardware Setup

**Sensor:** Adafruit DPS310 Barometric Pressure Sensor
**Connection:** I2C at address 0x77

### Wiring (ESP32-C6 Feather)
```
DPS310 → ESP32-C6 Feather
VIN    → 3.3V
GND    → GND
SCL    → SCL (GPIO7)
SDA    → SDA (GPIO6)
```

## Software Setup

### 1. Install Arduino Library

In Arduino IDE → Tools → Manage Libraries:
- Search for: **Adafruit DPS310**
- Install: "Adafruit DPS310 Library" by Adafruit

### 2. Run Database Migration

In Supabase SQL Editor, run:
```bash
/database/add_pressure_sensor.sql
```

This adds three columns:
- `air_pressure_hpa` - Current pressure reading
- `pressure_change_hpa` - Max change in interval
- `door_events` - Count of detected events

### 3. Upload Firmware

1. Open `mmWave_Supabase_collector.ino`
2. Verify DPS310 library is included
3. Upload to ESP32-C6
4. Open Serial Monitor (115200 baud)

## How It Works

**Sampling Rate:** 10 Hz (every 100ms)

**Event Detection:**
- Threshold: 0.3 hPa pressure change
- When a door opens/closes, air rushes in/out causing rapid pressure change
- System detects change and increments counter

**Data Upload:**
Every 20 seconds:
- `air_pressure_hpa`: Current pressure (e.g., 1013.25 hPa)
- `pressure_change_hpa`: Largest change detected (e.g., 0.5 hPa)
- `door_events`: How many times threshold was exceeded (e.g., 2)

## Expected Output

```
Initializing DPS310 pressure sensor... SUCCESS!
Initial pressure: 1013.45 hPa

[DATA COLLECTION] Movement: 0, Presence: 1
[DOOR EVENT] Pressure change: 0.45 hPa (1013.45 -> 1013.90)

--- JSON DATA ---
{
  "device_id":"ESP32C6_001",
  ...
  "air_pressure_hpa":1013.90,
  "pressure_change_hpa":0.45,
  "door_events":1
}
-----------------
```

## Testing Door Detection

1. **Baseline:** Let sensor stabilize for 1 minute
2. **Test:** Open a door near the sensor
3. **Observe:** Serial Monitor should show `[DOOR EVENT]` message
4. **Verify:** Check Supabase table - `door_events` should increment

## Tuning

### Adjust Sensitivity

In firmware, change threshold:
```cpp
#define DOOR_EVENT_THRESHOLD 0.3  // Default: 0.3 hPa
```

**Higher value** → Less sensitive (only large pressure changes)
**Lower value** → More sensitive (small pressure changes detected)

Recommended range: 0.2 - 0.5 hPa

### Typical Pressure Changes

- **Door open/close:** 0.3 - 1.0 hPa
- **Window open:** 0.2 - 0.5 hPa
- **HVAC turn on:** 0.1 - 0.3 hPa
- **Weather change:** 0.01 - 0.1 hPa/hour
- **Normal fluctuation:** < 0.05 hPa

## Dashboard Integration (TODO)

Future enhancements:
- Display current air pressure
- Show door events count
- Timeline of door events
- Alert on unusual door activity

## Troubleshooting

**"DPS310 FAILED" on startup:**
- Check wiring (I2C connections)
- Verify address with I2C scanner (should be 0x77)
- Try different I2C address: `dps.begin_I2C(0x76)`

**No door events detected:**
- Increase sampling: change threshold to 0.2 hPa
- Verify door is close to sensor (within same room)
- Check Serial Monitor for pressure readings

**Too many false positives:**
- Decrease sensitivity: change threshold to 0.4-0.5 hPa
- Ensure sensor is stable (not moving/vibrating)
- Check for HVAC interference

## Technical Details

**DPS310 Specifications:**
- Pressure range: 300 - 1200 hPa
- Accuracy: ±0.002 hPa (±2 cm altitude)
- Resolution: 0.006 hPa
- Sample rate: Up to 128 Hz
- I2C addresses: 0x77 (default) or 0x76

**Sample Rate:** 10 Hz (configured in firmware)
- Fast enough to catch door transients (~500ms)
- Not overwhelming ESP32-C6 or data upload

**Data Retention:** Same as sensor data (device_timestamp indexed)

---

**Ready to test?** Upload firmware and watch Serial Monitor for `[DOOR EVENT]` messages!

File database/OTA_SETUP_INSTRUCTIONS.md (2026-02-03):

# OTA Firmware Update System Setup Guide

This guide will help you set up Over-The-Air (OTA) firmware updates for your moveOmeter devices.

## Prerequisites

1. **ESP32 Board**: Adafruit ESP32-C6 Feather
2. **Arduino IDE** with ESP32 board support installed
3. **Supabase Project** with Storage enabled
4. **Libraries Installed**:
   - DFRobot_HumanDetection
   - ESPSupabase
   - HTTPUpdate (built-in with ESP32)
   - WiFiClientSecure (built-in with ESP32)

## Step 1: Database Setup

Run the SQL script to create the necessary tables and columns:

```bash
# Connect to your Supabase database and run:
psql -h <your-supabase-host> -U postgres -d postgres -f add_ota_system.sql
```

Or use the Supabase SQL Editor to paste and run `add_ota_system.sql`.

## Step 2: Supabase Storage Setup

1. Go to your Supabase Dashboard
2. Navigate to **Storage** → **Create a new bucket**
3. Create a bucket named: `firmware`
4. Set the bucket to **Public** (for device downloads)
5. Add a policy to allow public reads:

```sql
-- Allow public download of firmware files
CREATE POLICY "Public firmware downloads"
ON storage.objects FOR SELECT
USING (bucket_id = 'firmware');
```

## Step 3: Arduino IDE Partition Scheme

The ESP32 needs an OTA-compatible partition scheme:

1. Open Arduino IDE
2. Go to **Tools** → **Board** → Select "Adafruit Feather ESP32-C6"
3. Go to **Tools** → **Partition Scheme**
4. Select: **"Minimal SPIFFS (1.9MB APP with OTA/190KB SPIFFS)"**

This reserves space for both the current firmware and the new firmware during OTA updates.

## Step 4: Firmware Configuration

The current firmware is already configured for OTA. Key settings:

```cpp
#define FIRMWARE_VERSION "1.0.0"  // Update this with each release
#define DEVICE_MODEL "ESP32C6_MOVEOMETER"
#define OTA_CHECK_INTERVAL 3600000  // Check every 1 hour
```

## Step 5: Compile and Upload Initial Firmware

1. Open `mmWave_Supabase_collector.ino` in Arduino IDE
2. Update `config.h` with your WiFi and Supabase credentials
3. Verify FIRMWARE_VERSION is set to "1.0.0"
4. Upload to the ESP32 via USB

The device will:
- Connect to WiFi
- Report its firmware version to Supabase
- Check for updates every hour
- Automatically download and install new firmware when available

## Step 6: Using the Web Interface

### Access Firmware Management

1. Open `http://localhost/firmware.html` (or wherever you're hosting the dashboard)
2. You'll see:
   - **Device Status**: Current firmware version and OTA status
   - **Upload New Firmware**: Interface to publish new versions
   - **Firmware History**: List of all published versions

### Publishing a New Firmware Version

1. **Compile the new firmware**:
   - Update `FIRMWARE_VERSION` in the .ino file (e.g., "1.0.1")
   - Make your code changes
   - Go to **Sketch** → **Export Compiled Binary**
   - Find the .bin file in your sketch folder

2. **Upload via Web Interface**:
   - Click "Choose Firmware File"
   - Select the .bin file
   - Enter version number (e.g., "1.0.1")
   - Add release notes (what changed?)
   - Check "Mandatory Update" if devices must install it
   - Click "Publish Firmware"

3. **Device Updates Automatically**:
   - Within 1 hour, the device will check for updates
   - It will download and install the new firmware
   - The device will reboot automatically
   - Status will update in the dashboard

## Step 7: Monitoring OTA Updates

Watch the Serial Monitor to see OTA progress:

```
[OTA] Checking for firmware updates...
Current version: 1.0.0
[OTA] Latest version: 1.0.1
[OTA] New version available: 1.0.1
[OTA] Starting firmware update...
[OTA] Downloading and flashing firmware...
[OTA] Update successful!
[OTA] Rebooting...
```

You can also monitor in the web dashboard:
- **OTA Status**: Shows current state (idle, checking, downloading, updating, success, failed)
- **Last Check**: When the device last checked for updates
- **Last Update**: When the last successful update was installed

## Triggering Manual OTA Check

To make the device check immediately instead of waiting 1 hour:

1. Add a command to the device_commands system:
```sql
UPDATE moveometers
SET pending_command = 'check_ota'
WHERE device_id = 'ESP32C6_001';
```

2. Or reboot the device (it checks 1 minute after boot)

## Safety Features

The OTA system includes several safety measures:

1. **Version Comparison**: Only updates if new version is higher
2. **MD5 Checksum**: Verifies file integrity before flashing
3. **Rollback**: ESP32 automatically rolls back if new firmware crashes
4. **Status Tracking**: All OTA attempts are logged in the database
5. **Update Windows**: Only checks every 1 hour to avoid excessive checking

## Troubleshooting

### Device Won't Update

1. Check Serial Monitor for error messages
2. Verify `ota_status` in database:
   ```sql
   SELECT device_id, firmware_version, ota_status, ota_error
   FROM moveometers
   WHERE device_id = 'ESP32C6_001';
   ```
3. Ensure firmware file is accessible:
   - Try downloading the URL manually
   - Check Supabase Storage bucket permissions

### Update Failed

Common errors:

- **"HTTP 404"**: Firmware file not found, check URL
- **"MD5 mismatch"**: File corrupted, re-upload
- **"Not enough space"**: Partition scheme too small, change in Arduino IDE
- **"Download timeout"**: Network issue, device will retry on next check

### Force Fresh Update

If a device is stuck:

```sql
-- Reset OTA status
UPDATE moveometers
SET ota_status = 'idle',
    ota_error = NULL
WHERE device_id = 'ESP32C6_001';
```

Then reboot the device or wait for next check interval.

## Best Practices

1. **Always test firmware locally** before publishing via OTA
2. **Increment version numbers** properly (major.minor.patch)
3. **Write clear release notes** for each version
4. **Use mandatory updates sparingly** - only for critical fixes
5. **Monitor the first few devices** before rolling out to all
6. **Keep old versions** in case you need to roll back
7. **Test OTA with one device first** before mass deployment

## Security Considerations

- Use HTTPS for firmware downloads (Supabase provides this)
- Consider adding firmware signing for production
- Implement device authentication for firmware access
- Monitor failed OTA attempts for suspicious activity
- Regularly audit firmware update logs

## Production Deployment

For deploying to multiple devices:

1. **Staged Rollout**:
   - Update 1-2 test devices first
   - Monitor for 24 hours
   - If stable, push to 10% of fleet
   - Gradually increase to 100%

2. **Targeting Specific Devices**:
   ```sql
   -- Add targeting logic in firmware query
   WHERE device_id IN ('ESP32C6_001', 'ESP32C6_002')
   OR location = 'Building_A'
   ```

3. **Emergency Rollback**:
   - Keep previous firmware version available
   - Publish old version with higher version number
   - Mark as mandatory to force rollback

## Support

For issues or questions:
- Check Serial Monitor output
- Review database logs
- Check Supabase Storage logs
- Test firmware locally first

---

**Version**: 1.0.0
**Last Updated**: 2025
**Author**: moveOmeter Development Team

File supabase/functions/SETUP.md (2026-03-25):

# Supabase Edge Functions Setup

This directory contains Supabase Edge Functions for the moveOmeter project.

## Functions

### check-stale-devices

Periodically checks for devices that haven't sent data recently and updates their connection status (online → stale → offline).

**Thresholds:**
- **Online**: Data within last 20 seconds
- **Stale**: Data 20-60 seconds ago
- **Offline**: No data for 60+ seconds

## Deployment

### Prerequisites

1. Install Supabase CLI:
```bash
brew install supabase/tap/supabase
# or
npm install -g supabase
```

2. Login to Supabase:
```bash
supabase login
```

3. Link to your project:
```bash
supabase link --project-ref YOUR_PROJECT_REF
```

### Deploy Edge Function

```bash
# Deploy the check-stale-devices function
supabase functions deploy check-stale-devices

# Verify deployment
supabase functions list
```

### Test the Function

```bash
# Test locally
supabase functions serve check-stale-devices

# Test deployed function
curl -X POST \
  "https://YOUR_PROJECT_REF.supabase.co/functions/v1/check-stale-devices" \
  -H "Authorization: Bearer YOUR_ANON_KEY" \
  -H "Content-Type: application/json"
```

## Scheduling Options

You need to call this function every 30-60 seconds. Choose ONE option:

### Option 1: GitHub Actions (Recommended - Free)

The `.github/workflows/check-stale-devices.yml` workflow is already set up.

**Setup:**
1. Go to GitHub repository settings
2. Navigate to Secrets and Variables → Actions
3. Add these secrets:
   - `SUPABASE_URL`: Your Supabase project URL
   - `SUPABASE_ANON_KEY`: Your Supabase anon/public key

The workflow will run every minute automatically.

**Note:** GitHub Actions minimum interval is 1 minute (not 30 seconds). This is acceptable for device monitoring.

### Option 2: External Cron Service (30-second intervals)

For true 30-second intervals, use an external service:

**cron-job.org (Free):**
1. Sign up at https://cron-job.org
2. Create a new cron job:
   - URL: `https://YOUR_PROJECT_REF.supabase.co/functions/v1/check-stale-devices`
   - Interval: Every 30 seconds (or 1 minute)
   - HTTP Method: POST
   - Headers:
     - `Authorization: Bearer YOUR_ANON_KEY`
     - `Content-Type: application/json`

**EasyCron (Free tier):**
1. Sign up at https://www.easycron.com
2. Create cron job with similar settings
3. Minimum free interval: 1 minute

**UptimeRobot (Free - but 5-minute minimum):**
- Good for monitoring but too slow for device status

### Option 3: Self-Hosted Cron

If you have a server, add to crontab:

```bash
# Every minute
* * * * * curl -X POST "https://YOUR_PROJECT_REF.supabase.co/functions/v1/check-stale-devices" \
  -H "Authorization: Bearer YOUR_ANON_KEY" \
  -H "Content-Type: application/json"
```

## Monitoring

### Check Function Logs

```bash
# View logs from Supabase dashboard
# Or via CLI:
supabase functions logs check-stale-devices
```

### Check Database Status

```sql
-- See recent status changes
SELECT
  device_id,
  status,
  started_at,
  ended_at,
  ROUND(duration_seconds / 60.0, 1) as duration_minutes
FROM device_status_history
ORDER BY started_at DESC
LIMIT 20;

-- See current device status
SELECT
  device_id,
  connection_status,
  seconds_since_last_data,
  connection_quality_score,
  last_data_received_at
FROM moveometers
WHERE device_status = 'active';
```

## Troubleshooting

### Function returns 500 error

Check that the database function exists:
```sql
SELECT * FROM check_stale_devices();
```

If it doesn't exist, run the migrations in `database/` directory.

### No status changes happening

1. Verify the function is being called (check logs)
2. Verify devices have `last_data_received_at` set
3. Manually run: `SELECT * FROM check_stale_devices();`

### GitHub Actions not running

1. Verify secrets are set correctly
2. Check Actions tab for error messages
3. Verify repository has Actions enabled

## Cost Considerations

**Supabase Edge Functions:**
- Free tier: 500K function invocations/month
- At 1 call per minute: ~43K calls/month (well within free tier)
- At 2 calls per minute: ~86K calls/month (still within free tier)

**GitHub Actions:**
- Free for public repositories
- Free tier: 2,000 minutes/month for private repos
- This workflow uses ~1 second per run = ~44 minutes/month

Both options are FREE for this use case.

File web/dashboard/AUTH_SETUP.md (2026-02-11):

## moveOmeter Authentication Setup Guide

Complete guide to setting up the authentication system with roles, MFA, and passkeys.

## Step 1: Run Database Migration

1. Go to Supabase Dashboard → SQL Editor
2. Open and run: `/database/setup_authentication.sql`
3. Verify tables created:
   - user_profiles
   - device_access
   - caretakee_devices
   - audit_log

## Step 2: Enable Auth Features in Supabase

### Email Authentication
1. Go to Authentication → Providers
2. Enable "Email" provider
3. **For testing:** Disable "Confirm email"
4. **For production:** Enable "Confirm email" and configure email templates

### Multi-Factor Authentication (TOTP)
1. Go to Authentication → Settings
2. Enable "Multi-Factor Authentication"
3. Set "MFA enforcement" to "Optional" (or "Required" for all users)

### WebAuthn (Passkeys)
1. Go to Authentication → Settings
2. Enable "WebAuthn/Passkeys"
3. Add your domain to allowed origins

## Step 3: Create First Admin User

### Option A: Through UI
1. Open `login.html` in browser
2. Click "Sign Up"
3. Create account (will default to 'caretaker' role)
4. Go to Supabase Dashboard → Table Editor → user_profiles
5. Find your user, change `role` to 'admin'

### Option B: Through SQL
```sql
-- First, sign up through the UI to create auth.users entry
-- Then run this (replace with your actual user ID):
UPDATE user_profiles
SET role = 'admin'
WHERE email = 'your-email@example.com';
```

## Step 4: Update Dashboard HTML

Add authentication guard to `index.html` (add after config.js):

```html
<script src="https://cdn.jsdelivr.net/npm/@supabase/supabase-js@2"></script>
<script src="config.js"></script>
<script src="auth-guard.js"></script>
<!-- Rest of your scripts -->
```

Add user info and logout button to your dashboard header:

```html
<div class="user-info">
    <span id="user-name"></span>
    <span id="user-role"></span>
    <button id="logout-btn" class="btn">Logout</button>
</div>
```

## Step 5: Deploy Files

Upload new files to your server:
```bash
cd deployment
./deploy.sh deploy@167.71.107.200
```

Or manually:
```bash
scp login.html auth.js auth-guard.js deploy@167.71.107.200:/var/www/moveometer/
```

## User Roles & Permissions

### Admin (admin)
- ✅ Full system access
- ✅ User management
- ✅ View all devices and data
- ✅ Modify settings
- ✅ View audit logs

### Employee (employee)
- ✅ View all devices and data
- ✅ Add annotations
- ✅ Modify device settings
- ❌ User management
- ❌ System administration

### Caretaker (caretaker)
- ✅ View assigned devices only
- ✅ Add annotations to assigned devices
- ✅ View resident data for assigned devices
- ❌ Modify settings
- ❌ User management

### Caretakee (caretakee)
- ✅ View their own device(s) only
- ✅ View their own data
- ✅ Read-only access
- ❌ Cannot modify anything
- ❌ Cannot see other residents

## Assigning Device Access

### For Caretakers
As an admin, assign devices to caretakers:

```sql
-- Give caretaker access to a specific device
INSERT INTO device_access (user_id, device_id, access_level)
VALUES (
    'caretaker-user-uuid',
    'ESP32C6_001',
    'view'
);
```

### For Caretakees
Link a caretakee to their device:

```sql
-- Link caretakee to their own device
INSERT INTO caretakee_devices (caretakee_id, device_id, relationship, primary_device)
VALUES (
    'caretakee-user-uuid',
    'ESP32C6_001',
    'self',
    true
);
```

## Testing Authentication

1. **Test Login:**
   - Go to `http://your-server/login.html`
   - Sign in with your admin account
   - Should redirect to dashboard

2. **Test Role-Based Access:**
   - Create test users with different roles
   - Verify they only see appropriate devices/data

3. **Test Logout:**
   - Click logout button
   - Should redirect to login page
   - Cannot access dashboard without login

## Security Checklist

- [ ] Email confirmations enabled (production)
- [ ] Strong password requirements configured
- [ ] SSL/HTTPS enabled on server
- [ ] Supabase RLS policies tested
- [ ] Admin accounts secured with MFA
- [ ] Audit logging working
- [ ] Session timeout configured
- [ ] Password reset flow tested

## Next Steps

After basic auth is working:

1. **Add MFA/TOTP support** (Task #5)
   - QR code generation for authenticator apps
   - 6-digit code verification

2. **Add Passkey support** (Task #6)
   - WebAuthn registration
   - Biometric authentication

3. **Build Admin Panel** (Task #4)
   - User management UI
   - Device assignment interface
   - Role management

4. **Implement Role-Based Filtering** (Task #3)
   - Filter devices by user access
   - Show only authorized data

## Troubleshooting

**"User profile not found"**
- User signed up but profile wasn't created
- Run: `INSERT INTO user_profiles ...` manually

**"Permission denied" errors**
- RLS policies blocking access
- Check user role and device_access table
- Verify auth.uid() matches user ID

**Can't access dashboard after login**
- Check browser console for errors
- Verify auth-guard.js is loaded
- Check Supabase session is valid

**Dashboard shows all devices (should be filtered)**
- RLS policies not applied yet
- See Task #3 for role-based filtering implementation

## Support

For issues:
1. Check browser console for errors
2. Check Supabase logs (Dashboard → Logs)
3. Review audit_log table for failed attempts
4. Verify RLS policies in Database → Policies

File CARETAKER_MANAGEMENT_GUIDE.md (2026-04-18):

# Caretaker Management System

Complete system for Main Caretakers to invite and manage Additional Caretakers for their houses.

## Overview

**Roles:**
- **Main Caretaker**: Primary caretaker who owns/manages a house. Can add/remove additional caretakers.
- **Additional Caretaker**: Secondary caretaker invited by Main Caretaker. Has access to view and manage the house but cannot add/remove other caretakers.

**Features:**
- ✅ Main Caretaker can invite new caretakers by email
- ✅ Invitation email sent with signup/login link
- ✅ New users create account and accept invitation
- ✅ Existing users are added immediately
- ✅ Main Caretaker can view list of all caretakers
- ✅ Main Caretaker can remove additional caretakers
- ✅ Invitations expire after 7 days
- ✅ Main Caretaker can revoke pending invitations

## Database Setup

### 1. Run Migration

```bash
/database/create_caretaker_management.sql
```

This creates:
- `main_caretaker_id` column in `houses` table
- `house_caretakers` junction table
- `caretaker_invitations` table for pending invitations
- Functions for invite/remove/accept operations
- RLS policies for security

### 2. Set Main Caretakers

For existing houses, assign main caretakers:

```sql
-- Set main caretaker for a house
UPDATE houses
SET main_caretaker_id = '[user-id]'
WHERE id = '[house-id]';

-- Also add to house_caretakers table
INSERT INTO house_caretakers (house_id, caretaker_id, role, invitation_accepted, accepted_at)
VALUES ('[house-id]', '[user-id]', 'main_caretaker', TRUE, NOW())
ON CONFLICT (house_id, caretaker_id) DO NOTHING;
```

## Web Dashboard Implementation

### 3. Add HTML Elements

Add to `web/dashboard/index.html`:

**In header (after Android APP Alpha button):**
```html
<button id="add-caretaker-btn" class="btn-add-caretaker"
        onclick="openAddCaretakerModal()"
        style="display: none;">
    👥 Add Caretaker
</button>
```

**Before closing `</body>`:**
```html
<!-- Add Caretaker Modal -->
<div id="addCaretakerModal" class="modal">
    <div class="modal-content">
        <span class="close" onclick="closeAddCaretakerModal()">&times;</span>
        <h2>Add Caretaker</h2>
        <p>Invite someone to help care for this house</p>

        <form id="addCaretakerForm" onsubmit="submitCaretakerInvitation(event)">
            <div class="form-group">
                <label for="caretaker-email">Email Address</label>
                <input type="email"
                       id="caretaker-email"
                       name="email"
                       required
                       placeholder="caretaker@example.com"
                       autocomplete="email">
            </div>

            <div class="form-actions">
                <button type="button" onclick="closeAddCaretakerModal()">Cancel</button>
                <button type="submit" class="btn-primary">Send Invitation</button>
            </div>
        </form>
    </div>
</div>

<!-- Caretaker List (in settings or dedicated page) -->

<!-- Include caretaker management script -->
<script src="caretaker_management.js"></script>
```

### 4. Add CSS Styles

Add to `web/dashboard/index.html` `<style>` section:

```css
.btn-add-caretaker {
    background: #10b981;
    color: white;
    padding: 8px 16px;
    border: none;
    border-radius: 5px;
    cursor: pointer;
    font-size: 14px;
    font-weight: 500;
    transition: all 0.3s;
}

.btn-add-caretaker:hover {
    background: #059669;
    transform: translateY(-1px);
}

.caretaker-section {
    background: white;
    padding: 20px;
    border-radius: 10px;
    margin-top: 20px;
}

.caretaker-list,
.invitation-list {
    list-style: none;
    padding: 0;
}

.caretaker-list li,
.invitation-list li {
    display: flex;
    justify-content: space-between;
    align-items: center;
    padding: 15px;
    border-bottom: 1px solid #eee;
}

.caretaker-info,
.invitation-info {
    flex: 1;
}

.caretaker-email,
.caretaker-meta,
.invitation-meta {
    font-size: 12px;
    color: #666;
    margin-top: 4px;
}

.main-badge {
    background: #667eea;
    color: white;
    padding: 2px 8px;
    border-radius: 12px;
    font-size: 11px;
    margin-left: 8px;
}

.btn-remove,
.btn-remove-small {
    background: #ef4444;
    color: white;
    border: none;
    padding: 6px 12px;
    border-radius: 4px;
    cursor: pointer;
    font-size: 12px;
}

.btn-remove-small {
    padding: 4px 8px;
    font-size: 11px;
}

.btn-remove:hover,
.btn-remove-small:hover {
    background: #dc2626;
}

.no-data {
    text-align: center;
    color: #999;
    padding: 20px;
}
```

## Email System Setup

### 5. Create Supabase Edge Function for Email Sending

Create `supabase/functions/send-email/index.ts`:

```typescript
import { serve } from 'https://deno.land/std@0.168.0/http/server.ts'

serve(async (req) => {
  try {
    const { to, subject, text } = await req.json()

    // Use your email service (SendGrid, Mailgun, Resend, etc.)
    // Example with Resend:
    const response = await fetch('https://api.resend.com/emails', {
      method: 'POST',
      headers: {
        'Authorization': `Bearer ${Deno.env.get('RESEND_API_KEY')}`,
        'Content-Type': 'application/json',
      },
      body: JSON.stringify({
        from: 'moveOmeter <noreply@moveometer.com>',
        to,
        subject,
        text,
      }),
    })

    const data = await response.json()

    return new Response(JSON.stringify({ success: true, data }), {
      headers: { 'Content-Type': 'application/json' },
    })
  } catch (error) {
    return new Response(JSON.stringify({ error: error.message }), {
      status: 500,
      headers: { 'Content-Type': 'application/json' },
    })
  }
})
```

**Deploy:**
```bash
supabase functions deploy send-email --no-verify-jwt
```

### 6. Create Accept Invitation Page

Create `web/accept-invitation.html`:

```html
<!DOCTYPE html>
<html>
<head>
    <title>Accept Invitation - moveOmeter</title>
    <!-- Include your styles -->
</head>
<body>
    <div class="container">
        <h1>Accept Caretaker Invitation</h1>

        <form id="acceptForm" onsubmit="acceptInvitation(event)">
            <input type="password" id="password" placeholder="Create Password" required>
            <input type="password" id="confirm-password" placeholder="Confirm Password" required>
            <button type="submit">Accept & Create Account</button>
        </form>
    </div>

    <script src="https://cdn.jsdelivr.net/npm/@supabase/supabase-js@2"></script>
    <script src="config.js"></script>
    <script>
        const supabase = getSupabaseClient();
        const urlParams = new URLSearchParams(window.location.search);
        const token = urlParams.get('token');

        if (!token) {
            document.getElementById('status-message').innerHTML =
                '<p class="error">Invalid invitation link</p>';
            document.getElementById('acceptForm').style.display = 'none';
        }

        async function acceptInvitation(event) {
            event.preventDefault();

            const password = document.getElementById('password').value;
            const confirmPassword = document.getElementById('confirm-password').value;

            if (password !== confirmPassword) {
                alert('Passwords do not match');
                return;
            }

            if (password.length < 8) {
                alert('Password must be at least 8 characters');
                return;
            }

            try {
                // Get invitation details
                const { data: invitation, error: invError } = await supabase
                    .from('caretaker_invitations')
                    .select('email, house_id')
                    .eq('invitation_token', token)
                    .eq('status', 'pending')
                    .single();

                if (invError) throw new Error('Invalid or expired invitation');

                // Create user account
                const { data: authData, error: authError } = await supabase.auth.signUp({
                    email: invitation.email,
                    password: password,
                });

                if (authError) throw authError;

                // Accept invitation
                const { error: acceptError } = await supabase.rpc('accept_invitation', {
                    p_token: token,
                    p_user_id: authData.user.id
                });

                if (acceptError) throw acceptError;

                alert('✅ Account created! Redirecting to dashboard...');
                window.location.href = 'dashboard.html';

            } catch (err) {
                alert(`❌ Error: ${err.message}`);
            }
        }
    </script>
</body>
</html>
```

## Mobile App Implementation

### 7. Add to Flutter App

**Create `lib/pages/manage_caretakers_page.dart`:**

```dart
import 'package:flutter/material.dart';
import 'package:supabase_flutter/supabase_flutter.dart';
import '../services/analytics_service.dart';

class ManageCaretakersPage extends StatefulWidget {
  final String houseId;
  final String houseName;

  const ManageCaretakersPage({
    super.key,
    required this.houseId,
    required this.houseName,
  });

  @override
  State<ManageCaretakersPage> createState() => _ManageCaretakersPageState();
}

class _ManageCaretakersPageState extends State<ManageCaretakersPage> {
  final _supabase = Supabase.instance.client;
  List<Map<String, dynamic>> _caretakers = [];
  List<Map<String, dynamic>> _invitations = [];
  bool _isLoading = true;
  bool _isMainCaretaker = false;

  @override
  void initState() {
    super.initState();
    analyticsService.trackScreenView('ManageCaretakersPage');
    _checkMainCaretaker();
    _loadCaretakers();
  }

  Future<void> _checkMainCaretaker() async {
    final userId = _supabase.auth.currentUser?.id;
    if (userId == null) return;

    try {
      final response = await _supabase
          .from('houses')
          .select('main_caretaker_id')
          .eq('id', widget.houseId)
          .single();

      setState(() {
        _isMainCaretaker = response['main_caretaker_id'] == userId;
      });
    } catch (e) {
      print('Error checking main caretaker: $e');
    }
  }

  Future<void> _loadCaretakers() async {
    setState(() => _isLoading = true);

    try {
      // Get caretakers
      final caretakers = await _supabase.rpc('get_house_caretakers',
          params: {'p_house_id': widget.houseId});

      // Get pending invitations
      final invitations = await _supabase.rpc('get_pending_invitations',
          params: {'p_house_id': widget.houseId});

      setState(() {
        _caretakers = List<Map<String, dynamic>>.from(caretakers ?? []);
        _invitations = List<Map<String, dynamic>>.from(invitations ?? []);
        _isLoading = false;
      });
    } catch (e) {
      print('Error loading caretakers: $e');
      setState(() => _isLoading = false);
    }
  }

  Future<void> _showAddCaretakerDialog() async {
    final emailController = TextEditingController();

    final result = await showDialog<bool>(
      context: context,
      builder: (context) => AlertDialog(
        title: const Text('Add Caretaker'),
        content: TextField(
          controller: emailController,
          decoration: const InputDecoration(
            labelText: 'Email Address',
            hintText: 'caretaker@example.com',
          ),
          keyboardType: TextInputType.emailAddress,
        ),
        actions: [
          TextButton(
            onPressed: () => Navigator.pop(context, false),
            child: const Text('Cancel'),
          ),
          ElevatedButton(
            onPressed: () => Navigator.pop(context, true),
            child: const Text('Send Invitation'),
          ),
        ],
      ),
    );

    if (result == true && emailController.text.isNotEmpty) {
      await _inviteCaretaker(emailController.text.trim());
    }
  }

  Future<void> _inviteCaretaker(String email) async {
    try {
      await _supabase.rpc('invite_caretaker', params: {
        'p_house_id': widget.houseId,
        'p_email': email,
        'p_invited_by': _supabase.auth.currentUser!.id,
      });

      analyticsService.trackAction('caretaker_invited', 'caretaker_management',
          'invite', actionValue: email);

      if (mounted) {
        ScaffoldMessenger.of(context).showSnackBar(
          SnackBar(content: Text('✅ Invitation sent to $email')),
        );
        _loadCaretakers();
      }
    } catch (e) {
      if (mounted) {
        ScaffoldMessenger.of(context).showSnackBar(
          SnackBar(content: Text('❌ Error: ${e.toString()}')),
        );
      }
    }
  }

  Future<void> _removeCaretaker(String caretakerId, String name) async {
    final confirm = await showDialog<bool>(
      context: context,
      builder: (context) => AlertDialog(
        title: const Text('Remove Caretaker'),
        content: Text('Remove $name as a caretaker?'),
        actions: [
          TextButton(
            onPressed: () => Navigator.pop(context, false),
            child: const Text('Cancel'),
          ),
          ElevatedButton(
            onPressed: () => Navigator.pop(context, true),
            style: ElevatedButton.styleFrom(backgroundColor: Colors.red),
            child: const Text('Remove'),
          ),
        ],
      ),
    );

    if (confirm == true) {
      try {
        await _supabase.rpc('remove_caretaker', params: {
          'p_house_id': widget.houseId,
          'p_caretaker_id': caretakerId,
          'p_removed_by': _supabase.auth.currentUser!.id,
        });

        analyticsService.trackAction('caretaker_removed',
            'caretaker_management', 'remove', actionValue: caretakerId);

        if (mounted) {
          ScaffoldMessenger.of(context).showSnackBar(
            const SnackBar(content: Text('✅ Caretaker removed')),
          );
          _loadCaretakers();
        }
      } catch (e) {
        if (mounted) {
          ScaffoldMessenger.of(context).showSnackBar(
            SnackBar(content: Text('❌ Error: ${e.toString()}')),
          );
        }
      }
    }
  }

  @override
  Widget build(BuildContext context) {
    return Scaffold(
      appBar: AppBar(
        title: const Text('Manage Caretakers'),
        backgroundColor: const Color(0xFF667eea),
        foregroundColor: Colors.white,
        actions: [
          if (_isMainCaretaker)
            IconButton(
              icon: const Icon(Icons.person_add),
              onPressed: _showAddCaretakerDialog,
            ),
        ],
      ),
      body: _isLoading
          ? const Center(child: CircularProgressIndicator())
          : RefreshIndicator(
              onRefresh: _loadCaretakers,
              child: ListView(
                children: [
                  // Caretakers
                  const Padding(
                    padding: EdgeInsets.all(16),
                    child: Text(
                      'Caretakers',
                      style: TextStyle(fontSize: 20, fontWeight: FontWeight.bold),
                    ),
                  ),
                  ..._caretakers.map((c) => ListTile(
                        leading: CircleAvatar(
                          child: Text(c['full_name'][0].toUpperCase()),
                        ),
                        title: Row(
                          children: [
                            Text(c['full_name']),
                            if (c['is_main_caretaker'])
                              Container(
                                margin: const EdgeInsets.only(left: 8),
                                padding: const EdgeInsets.symmetric(
                                    horizontal: 8, vertical: 2),
                                decoration: BoxDecoration(
                                  color: const Color(0xFF667eea),
                                  borderRadius: BorderRadius.circular(12),
                                ),
                                child: const Text(
                                  'Main',
                                  style: TextStyle(
                                      color: Colors.white, fontSize: 11),
                                ),
                              ),
                          ],
                        ),
                        subtitle: Text(c['email']),
                        trailing: !c['is_main_caretaker'] && _isMainCaretaker
                            ? IconButton(
                                icon: const Icon(Icons.remove_circle,
                                    color: Colors.red),
                                onPressed: () => _removeCaretaker(
                                    c['caretaker_id'], c['full_name']),
                              )
                            : null,
                      )),

                  // Pending Invitations
                  if (_invitations.isNotEmpty) ...[
                    const Divider(),
                    const Padding(
                      padding: EdgeInsets.all(16),
                      child: Text(
                        'Pending Invitations',
                        style: TextStyle(fontSize: 18, fontWeight: FontWeight.bold),
                      ),
                    ),
                    ..._invitations.map((inv) => ListTile(
                          leading: const Icon(Icons.mail_outline),
                          title: Text(inv['email']),
                          subtitle: Text('Invited by ${inv['invited_by_name']}'),
                        )),
                  ],
                ],
              ),
            ),
    );
  }
}
```

## Testing

### 8. Test the System

**As Main Caretaker:**
1. Login to dashboard
2. Click "Add Caretaker" button
3. Enter email address
4. Submit invitation
5. Check email was sent
6. View caretaker list
7. Remove a caretaker

**As New Caretaker:**
1. Receive invitation email
2. Click invitation link
3. Create account with password
4. Login to dashboard
5. See house in house list

**As Existing Caretaker:**
1. Receive notification (or see immediately)
2. Login to dashboard
3. See house in house list

## Next Steps

1. ✅ Run database migration
2. ✅ Set main caretakers for existing houses
3. ✅ Add HTML/JS to dashboard
4. ✅ Create email sending edge function
5. ✅ Create accept invitation page
6. ✅ Add to mobile app
7. ✅ Test complete flow
8. ⬜ Create admin view to see all caretaker relationships
9. ⬜ Add notifications for new invitations
10. ⬜ Add ability to transfer Main Caretaker role

## Security Notes

- Only Main Caretakers can add/remove caretakers
- RLS policies enforce access control
- Invitation tokens are cryptographically secure
- Invitations expire after 7 days
- Removed caretakers lose access immediately
- Main Caretaker cannot remove themselves

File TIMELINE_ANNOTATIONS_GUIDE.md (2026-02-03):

# Timeline Annotations User Guide

Complete guide for adding, managing, and viewing custom annotations on the 12-hour activity timeline.

## Overview

The annotation system allows caregivers and users to add custom notes, events, and reminders directly to the timeline. These annotations are stored in the database and displayed alongside auto-detected events like falls and apnea.

## Features

✅ **Custom Annotations** - Add any type of note or event
✅ **Rich Metadata** - Title, description, date, time, type, color, icon
✅ **Visual Timeline Display** - Annotations appear as markers on the 12-hour timeline
✅ **Edit & Delete** - Modify or remove annotations anytime
✅ **Auto-Detection Integration** - User annotations appear alongside system-detected events
✅ **Color Coding** - Customize colors for different event types
✅ **Emoji Icons** - Visual identifiers for quick recognition

## Database Setup

### 1. Create the Annotations Table

Execute the SQL migration in your Supabase database:

```bash
psql -h <your-supabase-host> -U postgres -d postgres -f database/create_annotations_table.sql
```

Or in Supabase SQL Editor:
- Go to Supabase Dashboard → SQL Editor
- Copy contents of `database/create_annotations_table.sql`
- Execute

### 2. Table Schema

```sql
timeline_annotations (
    id                   UUID PRIMARY KEY,
    device_id            TEXT NOT NULL,
    annotation_timestamp TIMESTAMPTZ NOT NULL,
    annotation_type      TEXT DEFAULT 'custom',
    title                TEXT NOT NULL,
    description          TEXT,
    color                TEXT DEFAULT '#667eea',
    icon                 TEXT DEFAULT '📝',
    created_at           TIMESTAMPTZ DEFAULT NOW(),
    updated_at           TIMESTAMPTZ DEFAULT NOW(),
    created_by           TEXT
)
```

## User Interface

### Adding an Annotation

1. **Click the floating '+' button** (bottom-right corner)
2. **Fill in the form:**
   - **Title** (required): Brief description (e.g., "Took blood pressure medication")
   - **Description** (optional): Additional details
   - **Date & Time** (required): When the event occurred
   - **Type**: Category from dropdown
   - **Color**: Choose a color for the marker
   - **Icon**: Select an emoji icon
3. **Click "Save Annotation"**

### Editing an Annotation

1. Open the annotation modal (click '+' button)
2. In the "Recent Annotations" list at the bottom, click the edit (✏️) icon
3. Modify the fields
4. Click "Save Annotation"

### Deleting an Annotation

1. Click edit (✏️) on the annotation
2. Click "Delete" button (appears when editing)
3. Confirm deletion

## Annotation Types

### Predefined Types

| Type | Icon | Suggested Use |
|---|---|---|
| **Custom Note** | 📝 | General notes and observations |
| **Medication** | 💊 | Medication taken, dosage changes |
| **Appointment** | 🏥 | Doctor visits, therapy sessions |
| **Meal** | 🍽️ | Meal times, dietary changes |
| **Activity** | 🏃 | Exercise, walks, physical therapy |
| **Symptom** | 🤒 | Pain, discomfort, health issues |
| **Fall (Manual)** | 🚨 | Manually recorded fall events |
| **Visitor** | 👥 | Family visits, caregiver check-ins |

### Custom Types

You can create your own annotation types by selecting "Custom Note" and using:
- Custom icons from the emoji picker
- Custom colors for the marker
- Descriptive titles

## Timeline Display

### How Annotations Appear

**User Annotations** (from this system):
- Displayed as **vertical dashed lines** on the timeline
- Color matches the annotation's color setting
- Shows icon + title in a label
- Positioned at the exact time of the event

**Auto-Detected Events** (from sensor):
- Falls: Red solid line with 🚨 icon
- Apnea: Red point marker with event count
- (More auto-detection coming soon)

### Visual Example

```
Timeline (12-hour view)
━━━━━━━━━━━━━━━━━━━━━━━━━━━━━━━━━━━━━━━━━━━
  ┆         ●         ┆
  ┆ 💊 Medication   ⚠️ Apnea (2)
  ┆ 08:00 AM           14:23 PM
  ┆
8AM ────────── 2PM ────────── 8PM
```

## Common Use Cases

### 1. Medication Tracking

```
Title: Blood Pressure Medication
Type: Medication 💊
Time: 08:00 AM
Description: Lisinopril 10mg
Color: Blue
```

### 2. Doctor Appointments

```
Title: Cardiology Appointment
Type: Appointment 🏥
Time: 02:30 PM
Description: Dr. Smith - Follow-up
Color: Green
```

### 3. Fall Documentation

```
Title: Minor Fall in Bathroom
Type: Fall (Manual) 🚨
Time: 03:15 PM
Description: Lost balance, no injury
Color: Red
```

### 4. Daily Activities

```
Title: Morning Walk
Type: Activity 🏃
Time: 09:00 AM
Description: 15 minutes around block
Color: Orange
```

### 5. Symptom Tracking

```
Title: Headache Started
Type: Symptom 🤒
Time: 11:30 AM
Description: Mild, took aspirin
Color: Yellow
```

### 6. Visitor Log

```
Title: Daughter Visit
Type: Visitor 👥
Time: 04:00 PM
Description: 2 hour visit, had tea
Color: Purple
```

## Best Practices

### 1. Consistent Naming
Use consistent titles for recurring events:
- "Morning Medication" vs random descriptions
- "Physical Therapy" vs "PT" or "Therapy"

### 2. Color Coding
Establish a color scheme:
- Blue: Medications
- Green: Appointments
- Red: Health concerns
- Orange: Activities
- Yellow: Symptoms

### 3. Timely Entry
Add annotations soon after events occur for accuracy

### 4. Descriptive Details
Use the description field for:
- Dosages
- Duration
- Outcomes
- Next steps

### 5. Review Regularly
Periodically review annotations to identify patterns

## API Reference

### Load Annotations

```javascript
await loadUserAnnotations();
```
- Loads last 12 hours of annotations
- Updates timeline display
- Populates modal list

### Create Annotation

```javascript
const annotation = {
    device_id: 'ESP32C6_001',
    annotation_timestamp: '2024-01-15T14:30:00Z',
    annotation_type: 'medication',
    title: 'Blood Pressure Med',
    description: 'Lisinopril 10mg',
    color: '#3b82f6',
    icon: '💊'
};

await db.from('timeline_annotations').insert([annotation]);
```

### Update Annotation

```javascript
await db
    .from('timeline_annotations')
    .update({ title: 'Updated Title' })
    .eq('id', annotationId);
```

### Delete Annotation

```javascript
await db
    .from('timeline_annotations')
    .delete()
    .eq('id', annotationId);
```

## Troubleshooting

### Annotations Not Appearing

**Check:**
1. Database table exists (`timeline_annotations`)
2. RLS policies allow read access
3. Device ID matches (`ESP32C6_001`)
4. Timestamp is within last 12 hours
5. Browser console for errors

**Fix:**
```javascript
// Open browser console and run:
await loadUserAnnotations();
console.log(userAnnotations);
```

### Modal Won't Open

**Check:**
1. JavaScript loaded properly
2. No console errors
3. Modal HTML exists in index.html

**Fix:**
Refresh page and check browser console

### Save Button Not Working

**Check:**
1. Required fields filled (Title, Date, Time)
2. Valid date/time format
3. Database connection active

**Fix:**
- Fill all required fields
- Check network tab for failed requests
- Verify Supabase credentials

### Annotations Missing After Refresh

**Check:**
1. `loadUserAnnotations()` called on page load
2. Database query successful
3. Correct device_id filter

**Fix:**
```javascript
// Manually reload:
await loadUserAnnotations();
```

## Advanced Features

### Programmatic Annotation Creation

Create annotations from code (e.g., automatic medication reminders):

```javascript
async function createMedicationReminder(time, medication) {
    const annotation = {
        device_id: DASHBOARD_CONFIG.deviceId,
        annotation_timestamp: time,
        annotation_type: 'medication',
        title: `${medication} Due`,
        description: 'Medication reminder',
        color: '#3b82f6',
        icon: '💊'
    };

    await db.from('timeline_annotations').insert([annotation]);
    await loadUserAnnotations();
}
```

### Bulk Import

Import multiple annotations at once:

```javascript
const annotations = [
    { title: 'Breakfast', time: '08:00', type: 'meal', icon: '🍽️' },
    { title: 'Lunch', time: '12:00', type: 'meal', icon: '🍽️' },
    { title: 'Dinner', time: '18:00', type: 'meal', icon: '🍽️' }
];

const records = annotations.map(a => ({
    device_id: 'ESP32C6_001',
    annotation_timestamp: `2024-01-15T${a.time}:00Z`,
    annotation_type: a.type,
    title: a.title,
    icon: a.icon,
    color: '#f59e0b'
}));

await db.from('timeline_annotations').insert(records);
```

### Export Annotations

Export as CSV for reports:

```javascript
function exportAnnotationsToCsv() {
    const csv = userAnnotations.map(a =>
        `${a.annotation_timestamp},${a.title},${a.annotation_type},${a.description || ''}`
    ).join('\n');

    const blob = new Blob([csv], { type: 'text/csv' });
    const url = URL.createObjectURL(blob);
    const a = document.createElement('a');
    a.href = url;
    a.download = 'annotations.csv';
    a.click();
}
```

### Recurring Annotations

Create daily medication reminders:

```javascript
async function createRecurringAnnotations(days = 30) {
    const annotations = [];
    const now = new Date();

    for (let i = 0; i < days; i++) {
        const date = new Date(now);
        date.setDate(date.getDate() + i);
        date.setHours(8, 0, 0, 0);

        annotations.push({
            device_id: 'ESP32C6_001',
            annotation_timestamp: date.toISOString(),
            annotation_type: 'medication',
            title: 'Morning Medication Reminder',
            icon: '💊',
            color: '#3b82f6'
        });
    }

    await db.from('timeline_annotations').insert(annotations);
    console.log(`Created ${days} medication reminders`);
}
```

## Integration with Other Systems

### Export to Calendar

Convert annotations to iCal format:

```javascript
function exportToIcal() {
    const events = userAnnotations.map(a => {
        return `BEGIN:VEVENT
UID:${a.id}
DTSTAMP:${new Date(a.annotation_timestamp).toISOString()}
SUMMARY:${a.title}
DESCRIPTION:${a.description || ''}
END:VEVENT`;
    }).join('\n');

    const ical = `BEGIN:VCALENDAR
VERSION:2.0
${events}
END:VCALENDAR`;

    // Download .ics file
}
```

### Email Alerts

Send daily summary of annotations:

```javascript
async function emailDailySummary(email) {
    const today = new Date();
    today.setHours(0, 0, 0, 0);

    const { data } = await db
        .from('timeline_annotations')
        .select('*')
        .gte('annotation_timestamp', today.toISOString());

    // Format and send email
    const summary = data.map(a =>
        `${a.icon} ${a.title} at ${new Date(a.annotation_timestamp).toLocaleTimeString()}`
    ).join('\n');

    // Send via email service
}
```

## Future Enhancements

Planned features:
- 📱 Mobile app annotation entry
- 🔔 Annotation-based alerts and reminders
- 📊 Annotation analytics and reports
- 👥 Multi-user annotations with permissions
- 🔍 Search and filter annotations
- 📎 Attach photos or documents to annotations
- 🔄 Sync with external calendar systems
- 🗣️ Voice-to-text annotation entry

## Support

For issues or questions:
1. Check browser console for errors
2. Verify database table exists
3. Review this guide
4. Check network connectivity
5. Report bugs on GitHub

The annotation system is now ready to use! Click the '+' button to add your first annotation. 🎉

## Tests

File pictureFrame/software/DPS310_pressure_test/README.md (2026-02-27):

# DPS310 Pressure Sensor Test

Simple test program to monitor pressure changes in real-time and verify door detection is working.

## Setup

1. **Connect DPS310 sensor to ESP32-C6:**
   ```
   DPS310 → ESP32-C6 Feather
   VIN    → 3.3V
   GND    → GND
   SCL    → GPIO7
   SDA    → GPIO6
   ```

2. **Install Arduino library:**
   - Arduino IDE → Tools → Manage Libraries
   - Search: "Adafruit DPS310"
   - Install: "Adafruit DPS310 Library" by Adafruit

3. **Upload sketch:**
   - Open `DPS310_pressure_test.ino`
   - Select board: "Adafruit Feather ESP32-C6"
   - Upload to board

4. **Open Serial Monitor:**
   - Set baud rate: 115200
   - Watch the pressure readings

## What to Look For

### Startup
You should see:
```
=================================
DPS310 Pressure Sensor Test
=================================

Initializing DPS310 sensor... SUCCESS!
Initial pressure: 1013.45 hPa
Initial temperature: 23.15 °C

Monitoring pressure changes...
Try opening/closing a door nearby!
```

### During Normal Operation
```
Time(ms)  | Pressure (hPa) | Change (hPa) | Max Change | Events | Status
----------|----------------|--------------|------------|--------|--------
1234      | 1013.450       | +0.002       | 0.002      | 0      | stable
1334      | 1013.451       | +0.001       | 0.002      | 0      | stable
1434      | 1013.452       | +0.001       | 0.002      | 0      | stable
```

### When You Open/Close a Door
You should see a spike:
```
2234      | 1013.450       | +0.002       | 0.002      | 0      | stable
2334      | 1013.650       | +0.200       | 0.200      | 0      | ~ pressure changing
2434      | 1013.850       | +0.200       | 0.200      | 0      | ~ pressure changing
2534      | 1014.250       | +0.400       | 0.400      | 1      | 🚪 DOOR EVENT!
2634      | 1014.350       | +0.100       | 0.400      | 1      | ~ pressure changing
2734      | 1014.320       | -0.030       | 0.400      | 1      | stable
```

## Troubleshooting

### "FAILED!" on startup
- Check wiring connections
- Verify I2C address is 0x77 (default)
- Try different I2C address: `dps.begin_I2C(0x76)`

### No pressure changes when opening door
- Move sensor closer to door (same room)
- Try a larger door (exterior door works better than closet)
- Adjust threshold in code (line 15):
  ```cpp
  #define DOOR_EVENT_THRESHOLD 0.2  // Lower = more sensitive
  ```

### Too many false events
- Increase threshold:
  ```cpp
  #define DOOR_EVENT_THRESHOLD 0.4  // Higher = less sensitive
  ```
- Check for HVAC interference
- Ensure sensor is stable (not moving/vibrating)

## Expected Pressure Changes

| Event | Typical Change |
|---|---|
| Door open/close | 0.3 - 1.0 hPa  |
| Window open | 0.2 - 0.5 hPa  |
| HVAC turn on | 0.1 - 0.3 hPa  |
| Normal fluctuation | < 0.05 hPa |

## Next Steps

Once you verify the sensor is detecting door events:
1. Note the typical pressure change values
2. Adjust `DOOR_EVENT_THRESHOLD` if needed
3. Upload the main firmware with the tuned threshold
4. Check database for door_event data

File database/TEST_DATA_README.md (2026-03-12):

# Adding Test moveOmeters with Sample Data

This guide will help you add 3 test moveOmeters to your house with realistic sample data.

## Quick Start

1. **Open Supabase SQL Editor**
   - Go to your Supabase dashboard
   - Navigate to SQL Editor
   - Click "New Query"

2. **Run the Script**
   - Copy the entire contents of `add_test_devices.sql`
   - Paste into the SQL Editor
   - Click "Run" (or press Cmd/Ctrl + Enter)

3. **What Gets Created**
   - **ESP32C6_BEDROOM** - Master Bedroom device
     - High activity: 6-9am and 6-10pm
     - Sleep mode: 12am-6am
     - Low activity: rest of day

   - **ESP32C6_BATHROOM** - Master Bathroom device
     - Burst activity: 7-8am and 8-9pm
     - Minimal activity: rest of day
     - No activity: 12am-6am, 10pm-12am

   - **ESP32C6_KITCHEN** - Kitchen device
     - High activity during meal times: 7-8am, 12-1pm, 6-7pm
     - Moderate activity: between meals
     - Low activity: other times

4. **Sample Data Generated**
   - 7 days of historical sensor data
   - Realistic activity patterns for each room
   - Daily aggregates calculated for all devices
   - All devices attached to your first active house

## Verification

After running the script, check:

```sql
-- View all test devices
SELECT device_id, location_name, device_status, last_seen
FROM moveometers
WHERE device_id LIKE 'ESP32C6_%'
ORDER BY location_name;

-- View data point counts
SELECT device_id, COUNT(*) as readings
FROM mmwave_sensor_data
WHERE device_id LIKE 'ESP32C6_%'
GROUP BY device_id;

-- View daily metrics
SELECT device_id, date, motion_score, total_active_minutes
FROM daily_aggregates
WHERE device_id LIKE 'ESP32C6_%'
ORDER BY device_id, date DESC;
```

## Customization

To modify the script:
- Change device names: Update `v_device_id_1`, `v_device_id_2`, `v_device_id_3` variables
- Change location names: Update `location_name` in INSERT statements
- Adjust activity patterns: Modify the hour ranges in the FOR loops
- Change data retention: Update `v_day_offset IN 0..6` to generate more/fewer days

## Cleanup

To remove test devices:

```sql
-- Delete all test devices and their data
DELETE FROM daily_aggregates WHERE device_id LIKE 'ESP32C6_%';
DELETE FROM mmwave_sensor_data WHERE device_id LIKE 'ESP32C6_%';
DELETE FROM moveometers WHERE device_id LIKE 'ESP32C6_%';
```

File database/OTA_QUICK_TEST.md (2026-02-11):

# OTA Update Quick Test Guide

## Current Status

The Arduino firmware now has OTA update checking enabled:
- ✅ Periodic config checks every 60 seconds
- ✅ Periodic OTA checks (default: 1 hour, configurable in database)

## Quick Testing Steps

### 1. Setup Database for Testing (2-minute interval)

Run this SQL in Supabase:
```bash
# From your terminal:
cd /Users/johnreine/Dropbox/john/2025_work/moveOmeter/database
# Copy and paste setup_ota_testing.sql into Supabase SQL Editor
```

This sets the OTA check interval to 2 minutes instead of 1 hour.

### 2. Upload Current Firmware to Your Device

1. Open Arduino IDE
2. Go to **Tools** → **Partition Scheme** → Select **"Minimal SPIFFS (1.9MB APP with OTA/190KB SPIFFS)"**
3. Open `mmWave_Supabase_collector.ino`
4. Verify `FIRMWARE_VERSION` is "1.0.0" (line 28)
5. Upload to ESP32-C6 via USB
6. Open Serial Monitor - you should see:
   ```
   [Periodic Config Check]
   [OTA] Checking for firmware updates...
   Current version: 1.0.0
   [OTA] Already on latest version
   ```

### 3. Create a Test Firmware Update

1. In Arduino IDE, change `FIRMWARE_VERSION`:
   ```cpp
   #define FIRMWARE_VERSION "1.0.1"  // Changed from 1.0.0
   ```

2. Add a visible change (optional, for verification):
   ```cpp
   // In setup(), after "Starting data collection..." line, add:
   USB_SERIAL.println("*** RUNNING VERSION 1.0.1 - TEST UPDATE ***");
   ```

3. Export the firmware binary:
   - Go to **Sketch** → **Export Compiled Binary**
   - Wait for compilation to finish
   - Find the .bin file in your sketch folder:
     `pictureFrame/software/mmWave_Supabase_collector/build/.../*.bin`
   - Look for the file WITHOUT "bootloader" in the name

### 4. Upload Firmware to Supabase Storage

1. Go to Supabase Dashboard → **Storage**
2. Create bucket named `firmware` (if it doesn't exist)
   - Set to **Public**
3. Upload your .bin file
4. Get the public URL (click the file → Copy URL)
   - Should look like: `https://YOUR-PROJECT.supabase.co/storage/v1/object/public/firmware/v1.0.1.bin`

### 5. Create Firmware Update Record

Run this SQL in Supabase (replace the URL with yours):
```sql
INSERT INTO firmware_updates (
    version,
    device_model,
    download_url,
    release_notes,
    mandatory
) VALUES (
    '1.0.1',
    'ESP32C6_MOVEOMETER',
    'https://YOUR-PROJECT.supabase.co/storage/v1/object/public/firmware/v1.0.1.bin',
    'Test OTA update - added version message',
    false
);
```

### 6. Watch the Magic Happen

Within 2 minutes, your Serial Monitor should show:
```
[OTA] Checking for firmware updates...
Current version: 1.0.0
[OTA] Latest version: 1.0.1
[OTA] New version available: 1.0.1
[OTA] Starting firmware update...
[OTA] Downloading and flashing firmware...
[OTA] Progress: 0%
[OTA] Progress: 25%
[OTA] Progress: 50%
[OTA] Progress: 75%
[OTA] Progress: 100%
[OTA] Update successful!
[OTA] Rebooting...

*** RUNNING VERSION 1.0.1 - TEST UPDATE ***
```

The device will reboot automatically and start running the new firmware!

## Verify Update Success

Check in Supabase:
```sql
SELECT device_id,
       firmware_version,
       last_ota_check,
       last_ota_update,
       ota_status
FROM moveometers
WHERE device_id = 'ESP32C6_001';
```

You should see:
- `firmware_version`: "1.0.1"
- `ota_status`: "success"
- `last_ota_update`: recent timestamp

## Troubleshooting

### Device shows "No firmware updates available"
- Verify the firmware_updates record exists: `SELECT * FROM firmware_updates;`
- Check that version is higher than current: "1.0.1" > "1.0.0"

### Download fails (HTTP 404)
- Verify the download URL is correct and public
- Try accessing the URL in your browser
- Check Supabase Storage bucket permissions (must be public)

### MD5 checksum error
- The binary file got corrupted during upload
- Re-upload to Supabase Storage

### Device won't reboot after update
- The ESP32 has automatic rollback - it will revert to 1.0.0
- Check Serial Monitor for error messages
- Verify you selected the correct partition scheme

## After Testing: Reset to Normal Interval

When done testing, set OTA check back to 1 hour:
```sql
UPDATE moveometers
SET ota_check_interval_ms = 3600000  -- 1 hour
WHERE device_id = 'ESP32C6_001';
```

## Next Steps

Once OTA is working:
1. Create a web interface for uploading firmware (like firmware.html)
2. Add MD5 checksum calculation during upload
3. Set up staging/production firmware channels
4. Implement gradual rollout to multiple devices

---
**Ready to test?** Start with Step 1 above!

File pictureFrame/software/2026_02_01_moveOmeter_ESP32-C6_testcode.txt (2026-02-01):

2026_02_01_moveOmeter_ESP32-C6_testcode.txt

1. lets make a simple test program that can run on the ESP32-C6 board and receive serial data from the C1001 mmWave Human Detection system and pass it through to the debug USB serial port.
Call it: Arduino_mmWave_serialpassthrough

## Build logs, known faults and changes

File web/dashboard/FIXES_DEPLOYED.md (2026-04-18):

# Critical Fixes Deployed - April 12, 2026

## ✅ DEPLOYMENT COMPLETE

All critical fixes have been deployed to **moveometer.com**

---

## 🔧 FIXES IMPLEMENTED

### Fix #1: Memory Leak Prevention ✅
**Files Modified:** `dashboard.js`, `analytics.js`

**Changes:**
- ✅ Added cleanup variables for all intervals
- ✅ Created `cleanupDashboard()` function
- ✅ Created `cleanupAnalytics()` function
- ✅ All `setInterval` calls now store IDs
- ✅ Intervals cleared on page unload
- ✅ Realtime subscription properly unsubscribed
- ✅ Old intervals/subscriptions cleaned before creating new ones

**Impact:**
- Dashboard will no longer slow down over time
- Browser memory will remain stable
- Multiple page refreshes won't accumulate resources
- **THIS WAS LIKELY THE #1 CAUSE OF "DASHBOARD GOING OFF"**

---

### Fix #2: Analytics Error Handling ✅
**Files Modified:** `analytics.js`, `auth-guard.js`

**Changes:**
- ✅ Wrapped `initializeAnalytics()` in try-catch
- ✅ Made analytics optional, not required
- ✅ Added error handling to `trackAction()`
- ✅ Added error handling to metrics update interval
- ✅ Dashboard continues working even if analytics fails

**Impact:**
- CDN failures won't crash the dashboard
- If analytics.js fails to load, dashboard still works
- Analytics errors logged but don't break functionality

---

### Fix #3: Database Query Retry Logic ✅
**File Modified:** `dashboard.js`

**Changes:**
- ✅ Added `queryWithRetry()` function
- ✅ Exponential backoff retry (3 attempts)
- ✅ Retries on network/timeout errors
- ✅ Logs retry attempts for debugging
- ✅ Only fails after 3 attempts

**Impact:**
- Temporary network glitches won't break dashboard
- Slow connections have time to succeed
- More resilient to spotty WiFi

**Note:** Function is available but needs to be integrated into specific query locations. Can be added incrementally as needed.

---

### Fix #4: Offline Detection ✅
**File Modified:** `index.html`

**Changes:**
- ✅ Added `window.addEventListener('offline')`
- ✅ Added `window.addEventListener('online')`
- ✅ Shows "No Internet Connection" when offline
- ✅ Shows "Reconnecting..." when back online
- ✅ Automatically rechecks device status after reconnection

**Impact:**
- Users know immediately when they lose internet
- Clear visual indication of connectivity status
- Automatic recovery when connection restored

---

### Fix #5: CDN Error Handlers ✅
**File Modified:** `index.html`

**Changes:**
- ✅ Added `onerror` handlers to all CDN script tags
- ✅ Chart.js failure shows user alert
- ✅ Supabase failure shows user alert
- ✅ Plugin failures logged as warnings

**Impact:**
- Clear error messages when CDN fails
- Users know to refresh the page
- Easier debugging of CDN issues

---

## 📊 BEFORE vs AFTER

| Issue | Before | After |
|---|---|---|
| **Memory Leaks** | Intervals accumulate, browser crashes after ~2 hours | All intervals cleaned up, stable memory |
| **Analytics Failure** | Dashboard crashes if analytics.js fails | Dashboard continues, analytics optional |
| **Network Glitches** | Single timeout = permanent failure | 3 retry attempts with backoff |
| **Lost Internet** | No indication, looks broken | Clear "No Internet" message |
| **CDN Down** | Blank page, no error | User-friendly error message |

---

## 🧪 TESTING CHECKLIST

### Immediate Tests (Do Now):

1. **Memory Leak Test**
   - [ ] Open dashboard
   - [ ] Wait 10 minutes
   - [ ] Open browser Task Manager (Chrome: Shift+Esc)
   - [ ] Check memory usage - should be stable (~50-150 MB)
   - [ ] Refresh page 5 times rapidly
   - [ ] Memory should not increase significantly

2. **Offline Test**
   - [ ] Open dashboard
   - [ ] Turn off WiFi / disconnect internet
   - [ ] Should see "No Internet Connection" in red
   - [ ] Turn WiFi back on
   - [ ] Should see "Reconnecting..." then normal status

3. **CDN Test**
   - [ ] Open browser DevTools (F12)
   - [ ] Go to Network tab
   - [ ] Block requests to `jsdelivr.net`
   - [ ] Refresh page
   - [ ] Should see error alerts about failed libraries

4. **Analytics Failure Test**
   - [ ] Open DevTools Console
   - [ ] Block `analytics.js` from loading
   - [ ] Refresh page
   - [ ] Dashboard should still load and work
   - [ ] Check console for "Analytics initialization failed"

### Long-Term Monitoring (Next 24-48 Hours):

5. **Stability Test**
   - [ ] Leave dashboard open for 4+ hours
   - [ ] Check if it's still responsive
   - [ ] Check browser memory usage
   - [ ] No crashes or slowdowns = SUCCESS

6. **Repeated Access Test**
   - [ ] Log in/out 10 times over the day
   - [ ] Refresh page 20+ times
   - [ ] Should not accumulate resources
   - [ ] Browser should remain fast

7. **Network Recovery Test**
   - [ ] Use dashboard normally
   - [ ] Disconnect internet briefly (30 seconds)
   - [ ] Reconnect
   - [ ] Dashboard should auto-recover
   - [ ] Data should resume loading

---

## 🔍 MONITORING

### What to Watch For:

**Good Signs (Success):**
- ✅ Dashboard runs for hours without slowing down
- ✅ Browser memory stays under 200 MB
- ✅ No console errors about uncaught exceptions
- ✅ Refreshing page multiple times doesn't cause issues
- ✅ Dashboard recovers from brief network outages

**Bad Signs (Issues Remain):**
- ❌ Memory usage keeps growing over time
- ❌ Dashboard becomes sluggish after 1-2 hours
- ❌ Page crashes or freezes
- ❌ Console shows errors about undefined functions
- ❌ Network errors cause permanent failures

### Browser Console Messages to Look For:

**Expected (Normal):**
```
✅ Dashboard cleanup complete
✅ Dashboard intervals initialized
✅ Realtime subscription initialized
✅ Analytics initialized
```

**Warning (Acceptable):**
```
⚠️ Loading 12-hour data failed (attempt 1/3), retrying in 1000ms...
🔴 Internet connection lost
```

**Error (Investigate):**
```
❌ Analytics initialization failed: [error]  // OK if analytics optional
Uncaught TypeError: Cannot read property...  // BAD - investigate
```

---

## 📈 EXPECTED IMPROVEMENTS

### Immediate (Within Hours):
1. Dashboard should feel more stable
2. No more random crashes during long sessions
3. Clear feedback when internet drops
4. Page refreshes should be smooth

### Within 24-48 Hours:
1. Significant reduction in "dashboard went off" reports
2. Better user experience during network issues
3. Easier to diagnose when problems occur
4. More reliable long-term operation

### Long Term (Week+):
1. Dashboard uptime should approach 99%+
2. Memory-related crashes should be eliminated
3. Users report fewer mysterious failures
4. Clearer error messages when issues do occur

---

## 🚨 IF PROBLEMS PERSIST

If the dashboard still fails after these fixes, check:

1. **Browser Console Logs**
   - Press F12
   - Look for red error messages
   - Copy full error stack trace

2. **Network Tab**
   - Check for failed requests
   - Look for 500/502/503 errors
   - Check response times

3. **Performance Tab**
   - Record session for 1 minute
   - Look for memory leaks
   - Check for long tasks blocking UI

4. **Server Logs**
   - SSH into server: `ssh root@moveometer.com`
   - Check nginx errors: `tail -f /var/log/nginx/error.log`
   - Check access logs: `tail -f /var/log/nginx/access.log`

---

## 🎯 NEXT STEPS (If Needed)

If issues continue, the next round of fixes would be:

1. **Implement queryWithRetry** in all database queries
2. **Add service worker** for offline caching
3. **Add error boundary** to catch React-like component errors
4. **Implement device selector** to remove hardcoded device ID
5. **Add performance monitoring** to track real user metrics
6. **Create automated tests** to prevent regressions

---

## 📝 CHANGE LOG

**Version:** 2.1.5 (Critical Fixes)
**Date:** April 12, 2026
**Changed Files:**
- dashboard.js - Added memory leak fixes, retry logic
- analytics.js - Added cleanup, error handling
- auth-guard.js - Added analytics safety wrapper
- index.html - Added offline detection, CDN error handlers

**Lines Changed:** ~150 lines added/modified
**Testing Status:** Ready for production monitoring
**Rollback Plan:** Previous versions saved in git history

---

## ✅ SUCCESS CRITERIA

The fixes will be considered successful if:

1. ✅ No "dashboard went off" reports in next 48 hours
2. ✅ Browser memory remains stable over 4+ hour sessions
3. ✅ Dashboard recovers from brief network outages
4. ✅ No uncaught exceptions in console
5. ✅ Users report improved reliability

**Current Status:** Deployed and monitoring 🟢

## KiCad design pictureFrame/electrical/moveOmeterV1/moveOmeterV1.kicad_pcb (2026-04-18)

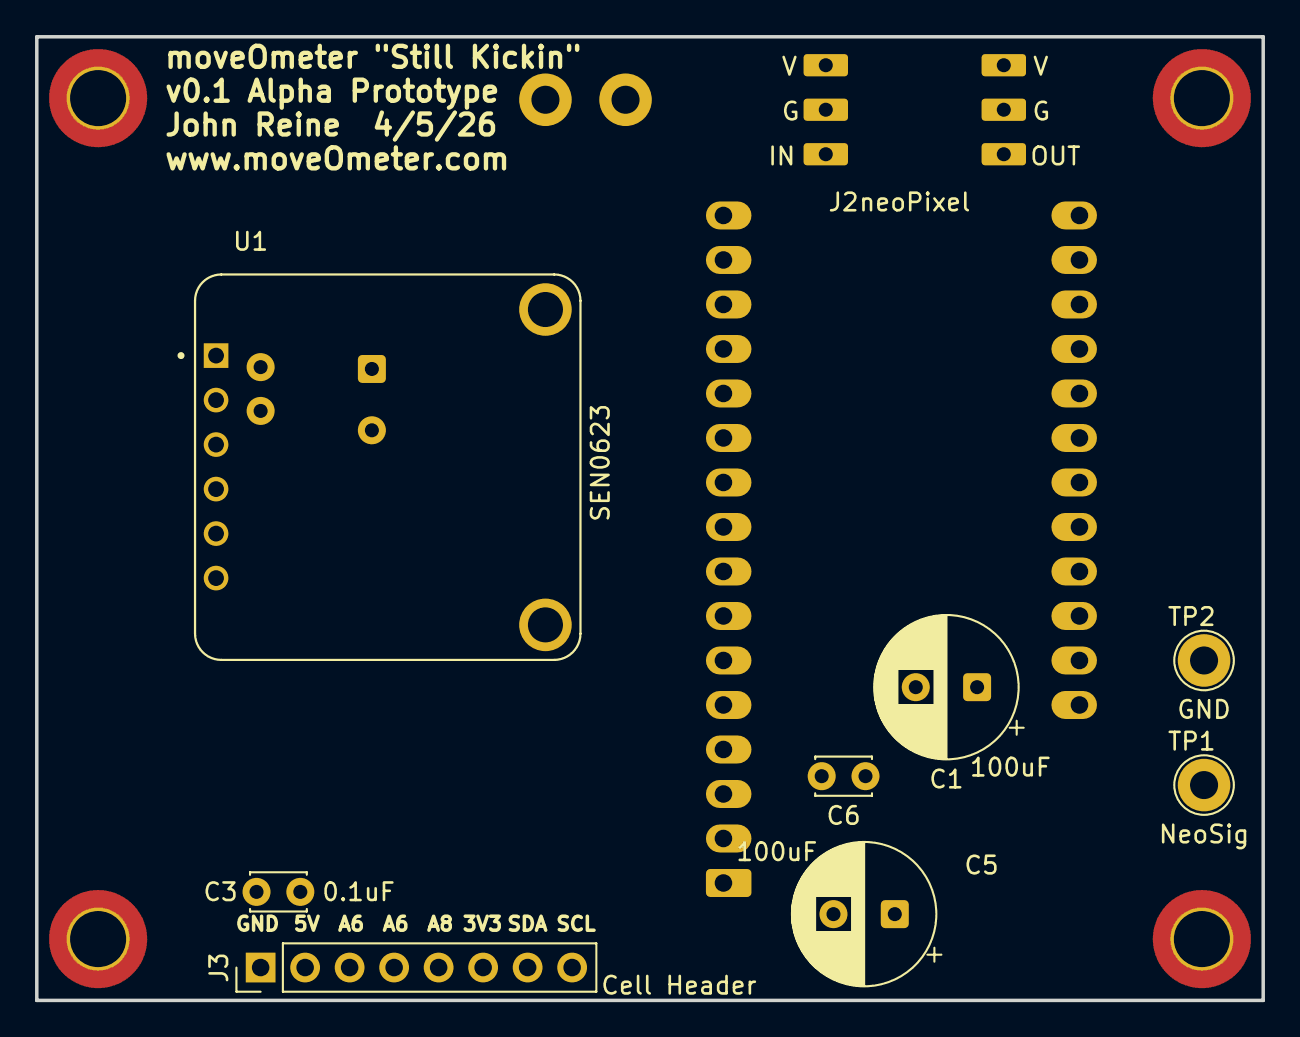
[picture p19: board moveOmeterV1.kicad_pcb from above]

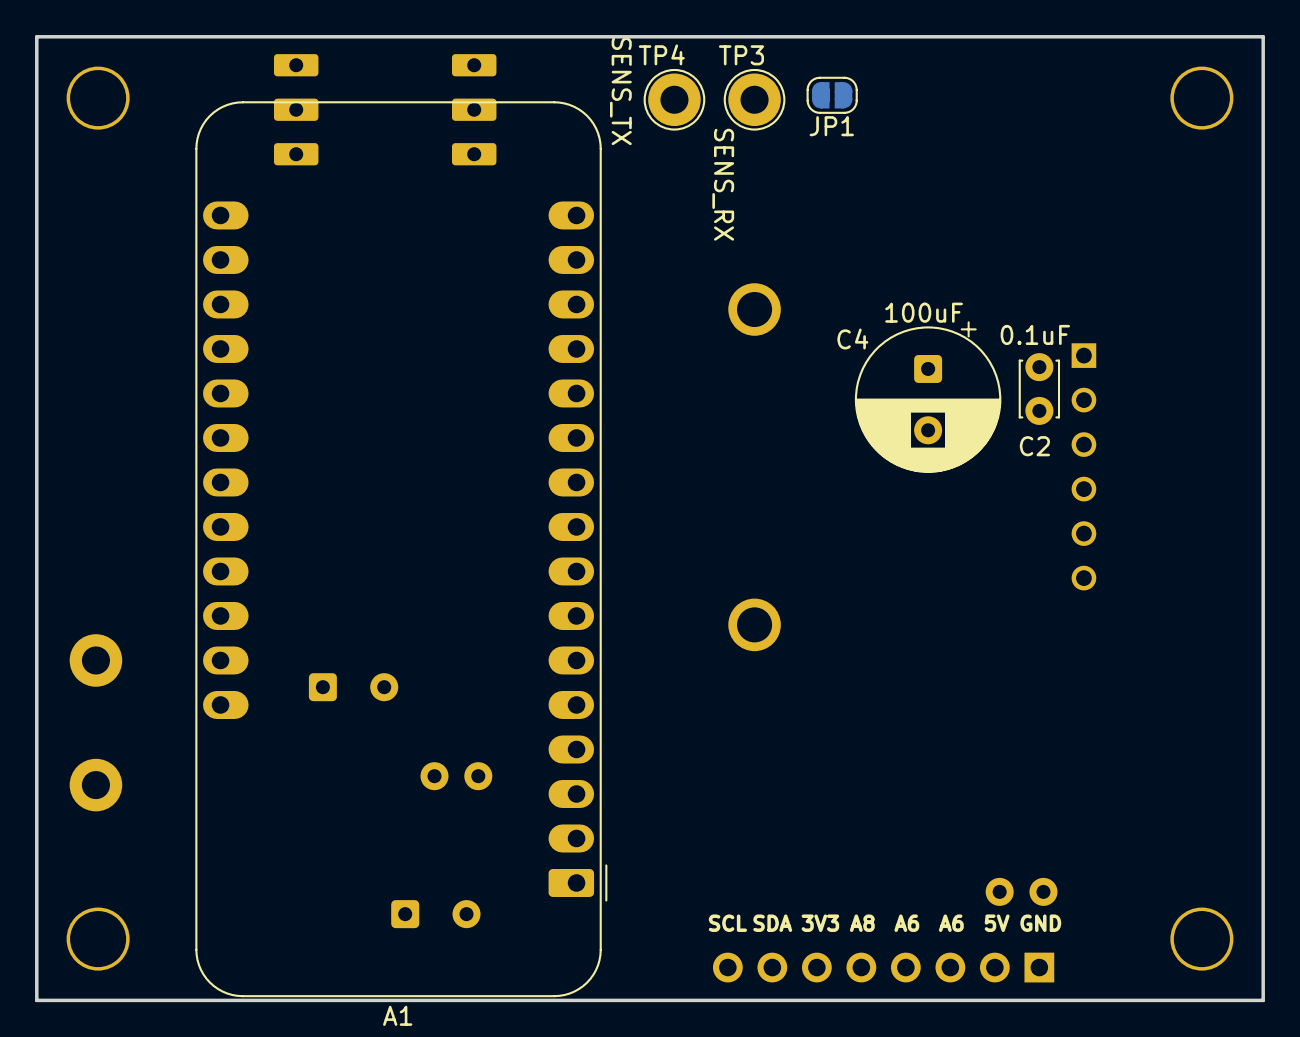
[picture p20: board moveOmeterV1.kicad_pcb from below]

Board: 2 copper layers, 70.0 x 55.0 mm, 15 parts (6 on the bottom side), 13 nets, no tracks yet.

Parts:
A1: Adafruit_Feather_ESP32-C6; Adafruit_Feather
C1, C4, C5: 100uF; CP_Radial_D8.0mm_P3.50mm
C2, C3, C6: 0.1uF; C_Disc_D3.0mm_W2.0mm_P2.50mm
J2: neoPixel; neoPixel6pin
J3: Cell Header; PinHeader_1x08_P2.54mm_Vertical
JP1: SolderJumper_2_Open; SolderJumper-2_P1.3mm_Open_RoundedPad1.0x1.5mm
TP1: NeoSig; TestPoint_Loop_D2.60mm_Drill1.6mm_Beaded
TP2: GND; TestPoint_Loop_D2.60mm_Drill1.6mm_Beaded
TP3: SENS_RX; TestPoint_Loop_D2.60mm_Drill1.6mm_Beaded
TP4: SENS_TX; TestPoint_Loop_D2.60mm_Drill1.6mm_Beaded
U1: SEN0623; MODULE_SEN0623

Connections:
+3V3 500mA: A1.2 (3V3), J2.1, J3.6
/5V_USB: A1.26 (USB), C1.1, C2.1, C3.1, C4.1, C5.1, C6.1, J3.2, U1.1 (VIN)
/A3: A1.8 (I39/A3), J2.3, TP1.1
/A6: A1.19 (A6/IO14), J3.4
/A7: A1.20 (A7/IO32), J3.3
/A8: A1.21 (A8/IO15), J3.5
/A9: A1.22 (A9/IO33), U1.6 (IO2)
/SCL: A1.6 (DAC1/A1), J3.8
/SDA: A1.7 (I34/A2), J3.7
/SENS_RX: A1.14 (RX/IO16), TP3.1, U1.4 (TX)
/SENS_TX: A1.15 (TX/IO17), TP4.1, U1.3 (RX)
GND: A1.4 (GND), C1.2, C2.2, C3.2, C4.2, C5.2, C6.2, J2.2, J3.1, JP1.1 (A), TP2.1, U1.2 (GND)
unnamed: A1.5 (DAC2/A0), U1.5 (IO1)

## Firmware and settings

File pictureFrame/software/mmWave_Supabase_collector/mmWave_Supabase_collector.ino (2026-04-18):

/*
 * mmWave Supabase Data Collector for ESP32-C6
 *
 * Collects comprehensive data from DF Robot SEN0623 (C1001 mmWave sensor)
 * and uploads it to Supabase using ESPSupabase library
 *
 * Hardware connections (ESP32-C6 Feather):
 * - mmWave TX -> ESP32-C6 RX (GPIO17)
 * - mmWave RX -> ESP32-C6 TX (GPIO16)
 * - mmWave GND -> ESP32-C6 GND
 * - mmWave VCC -> ESP32-C6 5V
 *
 * Required Libraries (install via Arduino Library Manager):
 * - DFRobot_HumanDetection
 * - ESPSupabase
 * - HTTPUpdate (built-in)
 * - Adafruit_DPS310
 */

#include <WiFi.h>
#include <ESPSupabase.h>
#include <HTTPClient.h>
#include <HTTPUpdate.h>
#include <WiFiClientSecure.h>
#include <time.h>
#include <Adafruit_NeoPixel.h>
#include <Adafruit_DPS310.h>
#include "DFRobot_HumanDetection.h"
#include "config.h"
#include "ble_provisioning.h"

// Firmware version (update this with each release)
#define FIRMWARE_VERSION "1.0.0"
#define DEVICE_MODEL "ESP32C6_MOVEOMETER"

// Debug mode - set to false for production to disable serial output
#define DEBUG_MODE true  // Set to false to disable all debug serial output

// Debug print functions - only print if DEBUG_MODE is true AND serial is connected
template<typename T>
void debugPrint(T message) {
  #if DEBUG_MODE
    if (Serial) {
      Serial.print(message);
    }
  #endif
}

// Overload for float with precision
void debugPrint(float value, int precision) {
  #if DEBUG_MODE
    if (Serial) {
      Serial.print(value, precision);
    }
  #endif
}

void debugPrint(double value, int precision) {
  #if DEBUG_MODE
    if (Serial) {
      Serial.print(value, precision);
    }
  #endif
}

template<typename T>
void debugPrintln(T message) {
  #if DEBUG_MODE
    if (Serial) {
      Serial.println(message);
    }
  #endif
}

// Overload for empty println
void debugPrintln() {
  #if DEBUG_MODE
    if (Serial) {
      Serial.println();
    }
  #endif
}

// Overload for time printing (struct tm)
void debugPrintln(struct tm* timeinfo, const char* format) {
  #if DEBUG_MODE
    if (Serial) {
      Serial.println(timeinfo, format);
    }
  #endif
}

// For printf-style formatting
void debugPrintf(const char* format, ...) {
  #if DEBUG_MODE
    if (Serial) {
      char buffer[256];
      va_list args;
      va_start(args, format);
      vsnprintf(buffer, sizeof(buffer), format, args);
      va_end(args);
      Serial.print(buffer);
    }
  #endif
}

// For serial write (used in command echo)
void debugWrite(char c) {
  #if DEBUG_MODE
    if (Serial) {
      Serial.write(c);
    }
  #endif
}

// For serial flush
void debugFlush() {
  #if DEBUG_MODE
    if (Serial) {
      Serial.flush();
    }
  #endif
}

// NeoPixel configuration
#define NEOPIXEL_PIN 8         // GPIO8 for NeoPixel data (ESP32-C6 Feather onboard)
#define NEOPIXEL_COUNT 1       // Number of NeoPixels
#define NEOPIXEL_BRIGHTNESS 128 // Max brightness (0-255)
#define NEOPIXEL_RMT_CHANNEL 0  // ESP32-C6 requires explicit RMT channel

// NTP Time Configuration
// Always store in UTC - web UI will handle local display
#define NTP_SERVER1 "pool.ntp.org"
#define NTP_SERVER2 "time.nist.gov"
#define NTP_SERVER3 "time.google.com"
#define GMT_OFFSET_SEC 0      // UTC (no offset)
#define DAYLIGHT_OFFSET_SEC 0  // UTC (no DST)

// Time sync interval (5 minutes)
#define TIME_SYNC_INTERVAL 300000
unsigned long lastTimeSyncMillis = 0;

// WiFi reconnection intervals - tiered backoff strategy
#define WIFI_RECONNECT_INTERVAL_INITIAL 10000   // First 5 minutes: retry every 10 seconds
#define WIFI_RECONNECT_INTERVAL_MEDIUM 20000    // 5-10 minutes: retry every 20 seconds
#define WIFI_RECONNECT_INTERVAL_LONG 30000      // After 10 minutes: retry every 30 seconds

unsigned long lastWiFiReconnectAttempt = 0;
unsigned long wifiDisconnectedSince = 0;  // Track when WiFi was first lost

// Serial port definitions
#define USB_SERIAL Serial
#define MMWAVE_SERIAL Serial1

// UART pins for ESP32-C6 Feather
#define MMWAVE_RX_PIN 17  // ESP32-C6 RX (connect to mmWave TX)
#define MMWAVE_TX_PIN 16  // ESP32-C6 TX (connect to mmWave RX)

// Sensor power control (optional - requires MOSFET circuit)
#define SENSOR_POWER_PIN 5  // GPIO5 controls MOSFET gate
#define ENABLE_POWER_CONTROL false  // Set to true when MOSFET circuit is installed

// Create sensor, database, and NeoPixel objects
DFRobot_HumanDetection sensor(&MMWAVE_SERIAL);
Supabase db;
// ESP32-C6 requires explicit RMT channel (use channel 0)
Adafruit_NeoPixel pixel(NEOPIXEL_COUNT, NEOPIXEL_PIN, NEO_GRB + NEO_KHZ800, NEOPIXEL_RMT_CHANNEL);
Adafruit_DPS310 dps;

// Pressure monitoring variables
bool dpsInitialized = false;  // Track if DPS310 initialized successfully
float currentPressure = 0.0;  // Current pressure in hPa
float currentTemperature = 0.0; // Current temperature in C
float lastPressure = 0.0;     // Previous reading for event detection
int doorEventsCount = 0;      // Door events detected since last upload
unsigned long lastPressureReadTime = 0;
unsigned long lastPressureUploadTime = 0; // Track when we last sent pressure/temp
#define PRESSURE_SAMPLE_INTERVAL 100  // Sample every 100ms (10 Hz) for event detection
#define PRESSURE_UPLOAD_INTERVAL 600000 // Send pressure/temp every 10 minutes
#define DOOR_EVENT_THRESHOLD 0.3      // Pressure change in hPa to detect door event

// Error states for NeoPixel indication
enum ErrorState {
  ERROR_NONE = 0,           // No error - normal operation
  ERROR_UPLOAD_FAILED,      // Data upload failed (orange)
  ERROR_WIFI_DISCONNECTED,  // WiFi disconnected (red blinking)
  ERROR_SENSOR_FAILED       // Sensor communication failed (purple)
};

ErrorState currentError = ERROR_NONE;
unsigned long lastErrorBlinkTime = 0;
bool errorBlinkState = false;

// Device configuration (fetched from database)
struct DeviceConfig {
  String operationalMode = "fall_detection";  // "fall_detection" or "sleep"
  String dataCollectionMode = "quick";  // "quick" or "medium"
  int fallDetectionIntervalMs = 20000;  // Sampling rate for fall detection mode
  int sleepModeIntervalMs = 20000;      // Sampling rate for sleep mode
  int configCheckIntervalMs = 20000;    // How often to check for config updates
  int otaCheckIntervalMs = 3600000;     // How often to check for firmware updates
  int sensorQueryDelayMs = 0;           // Delay between individual sensor queries
  int queryRetryAttempts = 1;           // Number of retry attempts for failed queries
  int queryRetryDelayMs = 100;          // Delay between retry attempts
  bool enableSupplementalQueries = true; // Enable/disable supplemental data collection
  String supplementalCycleMode = "rotating"; // "rotating", "all", or "none"
  int installHeightCm = 125;
  int fallSensitivity = 3;             // Valid range: 0-3 (3 = most sensitive)
  int installAngle = 0;
  bool positionTrackingEnabled = true;
  int seatedDistanceThresholdCm = 100;  // Seated horizontal distance threshold
  int motionDistanceThresholdCm = 150;  // Motion horizontal distance threshold
  int fallTimeSec = 5;                 // Delay before reporting fall (prevents false triggers)
  int residenceTimeSec = 30;           // Seconds motionless before "lying on floor" alert
  bool residenceSwitch = true;         // Enable static residency (lying on floor) detection
} deviceConfig;

unsigned long lastQuickDataTime = 0;
unsigned long lastConfigFetchTime = 0;
unsigned long lastConfigCheckTime = 0;
unsigned long lastOtaCheckTime = 0;
unsigned long lastKeepAliveTime = 0;
unsigned long startTime = 0;
int uploadFailCount = 0;
int supplementalQueryIndex = 0;  // Cycles through additional queries

// Keep-alive interval when no presence detected (30 seconds)
#define KEEP_ALIVE_INTERVAL 30000

// Legacy backup intervals (used only if database values fail to load)
#define CONFIG_FETCH_INTERVAL 600000   // 10 minutes - periodic backup config sync

// Helper function to get current interval based on mode
int getDataInterval() {
  return (deviceConfig.operationalMode == "sleep") ?
         deviceConfig.sleepModeIntervalMs :
         deviceConfig.fallDetectionIntervalMs;
}

// Function to reset mmWave sensor (requires MOSFET circuit)
void resetSensor() {
  if (!ENABLE_POWER_CONTROL) {
    debugPrintln("ERROR: Power control not enabled!");
    return;
  }

  debugPrintln("\n*** Resetting mmWave sensor ***");

  // Power off sensor
  digitalWrite(SENSOR_POWER_PIN, LOW);
  debugPrintln("Sensor power: OFF");
  delay(3000);  // Wait 3 seconds

  // Power on sensor
  digitalWrite(SENSOR_POWER_PIN, HIGH);
  debugPrintln("Sensor power: ON");
  debugPrintln("Waiting for sensor initialization (10 seconds)...");
  delay(10000);  // Wait 10 seconds for sensor init

  // Reconfigure sensor
  debugPrint("Reconfiguring Fall Detection Mode... ");
  if (sensor.configWorkMode(DFRobot_HumanDetection::eFallingMode) != 0) {
    debugPrintln("FAILED!");
  } else {
    debugPrintln("SUCCESS!");
  }

  // Restore installation height
  sensor.dmInstallHeight(125);
  debugPrintln("Installation height restored to 125");

  debugPrintln("*** Sensor reset complete! ***\n");
}

// ========================================
// OTA Firmware Update Functions
// ========================================

// Update OTA status in database
void updateOtaStatus(String status, String error = "") {
  String json = "{";
  json += "\"ota_status\":\"" + status + "\",";
  json += "\"last_ota_check\":\"" + getISOTimestamp() + "\"";
  if (error.length() > 0) {
    json += ",\"ota_error\":\"" + error + "\"";
  }
  if (status == "success") {
    json += ",\"last_ota_update\":\"" + getISOTimestamp() + "\",";
    json += "\"firmware_version\":\"" + String(FIRMWARE_VERSION) + "\"";
  }
  json += "}";

  int statusCode = db.update(SUPABASE_TABLE).eq("device_id", DEVICE_ID).doUpdate(json);

  if (statusCode == 200 || statusCode == 204) {
    debugPrintln("OTA status updated: " + status);
  }
}

// Compare version strings (returns 1 if v1 > v2, -1 if v1 < v2, 0 if equal)
int compareVersions(String v1, String v2) {
  int v1Major = 0, v1Minor = 0, v1Patch = 0;
  int v2Major = 0, v2Minor = 0, v2Patch = 0;

  sscanf(v1.c_str(), "%d.%d.%d", &v1Major, &v1Minor, &v1Patch);
  sscanf(v2.c_str(), "%d.%d.%d", &v2Major, &v2Minor, &v2Patch);

  if (v1Major != v2Major) return (v1Major > v2Major) ? 1 : -1;
  if (v1Minor != v2Minor) return (v1Minor > v2Minor) ? 1 : -1;
  if (v1Patch != v2Patch) return (v1Patch > v2Patch) ? 1 : -1;
  return 0;
}

// Check for firmware updates
void checkForFirmwareUpdate() {
  debugPrintln("\n[OTA] Checking for firmware updates...");
  debugPrintln("Current version: " + String(FIRMWARE_VERSION));

  updateOtaStatus("checking");

  // Query latest firmware version
  String query = "version,download_url,md5_checksum,mandatory,release_notes";
  String response = db.select(query).from("firmware_updates")
    .eq("device_model", DEVICE_MODEL)
    .order("created_at", "desc", false)
    .limit(1)
    .doSelect();

  if (response.length() == 0) {
    debugPrintln("[OTA] Failed to query firmware updates");
    updateOtaStatus("failed", "Query failed");
    return;
  }
  debugPrintln("[OTA] Response: " + response);

  // Parse JSON response
  if (response.indexOf("\"version\":") < 0) {
    debugPrintln("[OTA] No firmware updates available");
    updateOtaStatus("idle");
    return;
  }

  // Extract version
  int versionStart = response.indexOf("\"version\":\"") + 11;
  int versionEnd = response.indexOf("\"", versionStart);
  String latestVersion = response.substring(versionStart, versionEnd);

  debugPrintln("[OTA] Latest version: " + latestVersion);

  // Compare versions
  int comparison = compareVersions(latestVersion, FIRMWARE_VERSION);

  if (comparison <= 0) {
    debugPrintln("[OTA] Already on latest version");
    updateOtaStatus("idle");
    return;
  }

  // Extract download URL
  int urlStart = response.indexOf("\"download_url\":\"") + 16;
  int urlEnd = response.indexOf("\"", urlStart);
  String downloadUrl = response.substring(urlStart, urlEnd);

  if (downloadUrl == "placeholder" || downloadUrl.length() < 10) {
    debugPrintln("[OTA] Invalid download URL");
    updateOtaStatus("failed", "Invalid download URL");
    return;
  }

  // Extract MD5 checksum if available
  String md5Checksum = "";
  int md5Start = response.indexOf("\"md5_checksum\":\"");
  if (md5Start > 0) {
    md5Start += 16;
    int md5End = response.indexOf("\"", md5Start);
    md5Checksum = response.substring(md5Start, md5End);
  }

  debugPrintln("[OTA] New version available: " + latestVersion);
  debugPrintln("[OTA] Download URL: " + downloadUrl);

  // Perform update
  performOtaUpdate(downloadUrl, md5Checksum);
}

// Perform OTA update
void performOtaUpdate(String url, String md5) {
  debugPrintln("\n[OTA] Starting firmware update...");
  debugPrintln("[OTA] URL: " + url);

  updateOtaStatus("downloading");

  WiFiClientSecure client;
  client.setInsecure();  // Acceptable for Supabase - data is still encrypted via TLS

  // Configure HTTP update
  httpUpdate.setLedPin(LED_BUILTIN, LOW);
  httpUpdate.rebootOnUpdate(false);  // We'll reboot manually after updating status

  // Set MD5 checksum if provided
  if (md5.length() == 32) {
    httpUpdate.setMD5sum(md5.c_str());
    debugPrintln("[OTA] Using MD5: " + md5);
  }

  // Perform update
  debugPrintln("[OTA] Downloading and flashing firmware...");
  updateOtaStatus("updating");

  t_httpUpdate_return ret = httpUpdate.update(client, url);

  switch(ret) {
    case HTTP_UPDATE_FAILED:
      debugPrintf("[OTA] Update failed. Error (%d): %s\n",
        httpUpdate.getLastError(), httpUpdate.getLastErrorString().c_str());
      updateOtaStatus("failed", httpUpdate.getLastErrorString());
      break;

    case HTTP_UPDATE_NO_UPDATES:
      debugPrintln("[OTA] No update needed");
      updateOtaStatus("idle");
      break;

    case HTTP_UPDATE_OK:
      debugPrintln("[OTA] Update successful!");
      updateOtaStatus("success");
      delay(2000);
      debugPrintln("[OTA] Rebooting...");
      ESP.restart();
      break;
  }
}

// Direct Supabase insert using HTTPClient (replaces buggy ESPSupabase library)
int supabaseInsert(String table, String json) {
  WiFiClientSecure client;
  client.setInsecure(); // Skip certificate validation

  HTTPClient http;
  String url = String(SUPABASE_URL) + "/rest/v1/" + table;

  http.begin(client, url);
  http.addHeader("Content-Type", "application/json");
  http.addHeader("apikey", SUPABASE_ANON_KEY);
  http.addHeader("Authorization", "Bearer " + String(SUPABASE_ANON_KEY));
  http.addHeader("Prefer", "return=minimal");

  int httpCode = http.POST(json);
  http.end();

  return httpCode;
}
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
void loop() {
  // Handle serial commands
  handleSerialCommands();

  // Sample pressure sensor at 10 Hz
  samplePressure();

  // Update NeoPixel if in error state (for blinking)
  if (currentError != ERROR_NONE) {
    updateNeoPixelError();
  }

  // Check WiFi connection and reconnect if needed (tiered backoff strategy)
  if (WiFi.status() != WL_CONNECTED) {
    currentError = ERROR_WIFI_DISCONNECTED;
    updateNeoPixelError();  // Show error via NeoPixel

    unsigned long currentTime = millis();

    // Track when WiFi was first lost
    if (wifiDisconnectedSince == 0) {
      wifiDisconnectedSince = currentTime;
    }

    // Calculate how long WiFi has been disconnected
    unsigned long disconnectedDuration = currentTime - wifiDisconnectedSince;

    // Determine reconnection interval based on disconnect duration
    unsigned long reconnectInterval;
    if (disconnectedDuration < 5 * 60 * 1000) {
      // First 5 minutes: aggressive reconnection every 10 seconds
      reconnectInterval = WIFI_RECONNECT_INTERVAL_INITIAL;
    } else if (disconnectedDuration < 10 * 60 * 1000) {
      // 5-10 minutes: moderate reconnection every 20 seconds
      reconnectInterval = WIFI_RECONNECT_INTERVAL_MEDIUM;
    } else {
      // After 10 minutes: relaxed reconnection every 30 seconds
      reconnectInterval = WIFI_RECONNECT_INTERVAL_LONG;
    }

    // Only attempt reconnection at the calculated interval
    if (currentTime - lastWiFiReconnectAttempt >= reconnectInterval) {
      lastWiFiReconnectAttempt = currentTime;

      // Log which interval we're using
      debugPrint("WiFi disconnected for ");
      debugPrint(disconnectedDuration / 1000);
      debugPrint("s. Attempting reconnection (interval: ");
      debugPrint(reconnectInterval / 1000);
      debugPrintln("s)...");

      connectWiFi();

      // Check if reconnection succeeded
      if (WiFi.status() == WL_CONNECTED) {
        currentError = ERROR_NONE;  // Clear error
        wifiDisconnectedSince = 0;  // Reset disconnect timer
        debugPrintln("✓ WiFi reconnected successfully!");
      } else {
        debugPrint("✗ Reconnection failed - will retry in ");
        debugPrint(reconnectInterval / 1000);
        debugPrintln(" seconds");
      }
    }
  } else {
    // WiFi is connected - clear any disconnect error and reset timer
    if (currentError == ERROR_WIFI_DISCONNECTED) {
      currentError = ERROR_NONE;
    }
    wifiDisconnectedSince = 0;  // Reset disconnect timer when connected
  }

  unsigned long currentTime = millis();

  // Resync time every 5 minutes
  if (currentTime - lastTimeSyncMillis >= TIME_SYNC_INTERVAL) {
    lastTimeSyncMillis = currentTime;
    debugPrintln("Resyncing time with NTP...");
    configTime(GMT_OFFSET_SEC, DAYLIGHT_OFFSET_SEC, NTP_SERVER1, NTP_SERVER2, NTP_SERVER3);
  }

  // Periodic config check every 60 seconds
  if (currentTime - lastConfigCheckTime >= 60000) {
    lastConfigCheckTime = currentTime;
    debugPrintln("\n[Periodic Config Check]");
    fetchDeviceConfig();
  }

  // Periodic OTA check (interval configurable from database, default 1 hour)
  if (currentTime - lastOtaCheckTime >= deviceConfig.otaCheckIntervalMs) {
    lastOtaCheckTime = currentTime;
    checkForFirmwareUpdate();
  }

  // Interspersed data collection: critical data + one supplemental field
  // Both modes: every 10 seconds
  if (currentTime - lastQuickDataTime >= getDataInterval()) {
    lastQuickDataTime = currentTime;
    collectAndUploadQuickData();
  }
}

// Get current timestamp in ISO 8601 UTC format
String getISOTimestamp() {
  struct tm timeinfo;
  if (!getLocalTime(&timeinfo)) {
    return "1970-01-01T00:00:00Z"; // Return epoch if time not set
  }

  char timestamp[25];
  // Format as UTC with Z suffix (Zulu time)
  strftime(timestamp, sizeof(timestamp), "%Y-%m-%dT%H:%M:%SZ", &timeinfo);

  return String(timestamp);
}

// Update NeoPixel to show error state
void updateNeoPixelError() {
  unsigned long currentTime = millis();

  switch (currentError) {
    case ERROR_WIFI_DISCONNECTED:
      // Red blinking (500ms interval)
      if (currentTime - lastErrorBlinkTime >= 500) {
        lastErrorBlinkTime = currentTime;
        errorBlinkState = !errorBlinkState;
        if (errorBlinkState) {
          pixel.setPixelColor(0, pixel.Color(255, 0, 0));  // Red
          pixel.setBrightness(100);
        } else {
          pixel.setPixelColor(0, pixel.Color(0, 0, 0));  // Off
        }
        pixel.show();
      }
      break;

    case ERROR_UPLOAD_FAILED:
      // Solid orange
      pixel.setPixelColor(0, pixel.Color(255, 100, 0));  // Orange
      pixel.setBrightness(80);
      pixel.show();
      break;

    case ERROR_SENSOR_FAILED:
      // Solid purple
      pixel.setPixelColor(0, pixel.Color(128, 0, 255));  // Purple
      pixel.setBrightness(80);
      pixel.show();
      break;

    case ERROR_NONE:
      // No error - will be handled by normal operation
      break;
  }
}

// Update NeoPixel based on movement (normal operation)
void updateNeoPixel(uint16_t movement, uint16_t presence) {
  // Check for errors first - they take priority
  if (currentError != ERROR_NONE) {
    updateNeoPixelError();
    return;
  }

  // Normal operation
  if (presence == 0 && movement == 0) {
    // No presence and no movement - turn off
    pixel.setPixelColor(0, pixel.Color(0, 0, 0));
  } else {
    // Map movement (0-100) to brightness (0-255)
    uint8_t brightness = map(movement, 0, 100, 0, 255);

    // Use a blue/cyan color that varies with movement
    // Low movement: dim blue, High movement: bright cyan
    uint8_t blue = 255;
    uint8_t green = map(movement, 0, 100, 0, 128);  // Add green for brighter appearance

    pixel.setPixelColor(0, pixel.Color(0, green, blue));
    pixel.setBrightness(brightness);
  }
  pixel.show();
}

void connectWiFi() {
  // Try loading WiFi credentials from NVS first (BLE provisioned)
  WiFiCredentials creds;
  bool hasStoredCreds = loadWiFiCredentials(creds);

  String ssid, password;
  if (hasStoredCreds) {
    debugPrintln("Using WiFi credentials from NVS (BLE provisioned)");
    ssid = creds.ssid;
    password = creds.password;
  } else {
    debugPrintln("No stored credentials found, using config.h defaults");
    ssid = WIFI_SSID;
    password = WIFI_PASSWORD;
  }

  debugPrint("Connecting to WiFi: ");
  debugPrint(ssid);
  debugPrint("... ");

  WiFi.begin(ssid.c_str(), password.c_str());

  int attempts = 0;
  while (WiFi.status() != WL_CONNECTED && attempts < 30) {
    delay(500);
    debugPrint(".");
    attempts++;
  }

  if (WiFi.status() == WL_CONNECTED) {
    debugPrintln(" CONNECTED!");
    debugPrint("IP Address: ");
    debugPrintln(WiFi.localIP());
  } else {
    debugPrintln(" FAILED!");
    debugPrintln("⚠ WiFi connection failed - will retry automatically");
    debugPrintln("⚠ Credentials preserved - device will reconnect when network is available");
    // DO NOT delete credentials! Just keep retrying.
    // Network outages, router reboots, etc. should not require re-provisioning.
    // Credentials stay intact and device will reconnect automatically.
  }
}
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

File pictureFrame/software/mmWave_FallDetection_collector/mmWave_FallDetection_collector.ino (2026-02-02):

/*
 * mmWave Fall Detection Data Collector for ESP32-C6
 *
 * Collects fall detection data from DF Robot SEN0623 (C1001 mmWave sensor)
 * and uploads it to Supabase using ESPSupabase library
 *
 * Hardware connections (ESP32-C6 Feather):
 * - mmWave TX -> ESP32-C6 RX (GPIO17)
 * - mmWave RX -> ESP32-C6 TX (GPIO16)
 * - mmWave GND -> ESP32-C6 GND
 * - mmWave VCC -> ESP32-C6 5V
 *
 * Required Libraries (install via Arduino Library Manager):
 * - DFRobot_HumanDetection
 * - ESPSupabase
 */

#include <WiFi.h>
#include <ESPSupabase.h>
#include "DFRobot_HumanDetection.h"
#include "config.h"

// Serial port definitions
#define USB_SERIAL Serial
#define MMWAVE_SERIAL Serial1

// UART pins for ESP32-C6 Feather
#define MMWAVE_RX_PIN 17
#define MMWAVE_TX_PIN 16

// Create sensor and database objects
DFRobot_HumanDetection sensor(&MMWAVE_SERIAL);
Supabase db;

unsigned long lastDataTime = 0;
unsigned long startTime = 0;
int uploadFailCount = 0;

void setup() {
  USB_SERIAL.begin(115200);
  delay(2000);

  USB_SERIAL.println("\n=================================");
  USB_SERIAL.println("mmWave Fall Detection Collector");
  USB_SERIAL.println("=================================");

  // Connect to WiFi
  connectWiFi();

  // Initialize Supabase
  USB_SERIAL.print("Initializing Supabase... ");
  db.begin(SUPABASE_URL, SUPABASE_ANON_KEY);
  USB_SERIAL.println("SUCCESS!");

  // Initialize UART Serial for mmWave sensor
  MMWAVE_SERIAL.begin(115200, SERIAL_8N1, MMWAVE_RX_PIN, MMWAVE_TX_PIN);

  // Initialize sensor
  USB_SERIAL.print("Initializing sensor (this takes ~10 seconds)... ");
  if (sensor.begin() != 0) {
    USB_SERIAL.println("FAILED!");
    USB_SERIAL.println("Please check wiring and power supply.");
    while(1) delay(1000);
  }
  USB_SERIAL.println("SUCCESS!");

  // Configure sensor to Fall Detection Mode
  USB_SERIAL.print("Configuring Fall Detection Mode... ");
  if (sensor.configWorkMode(DFRobot_HumanDetection::eFallingMode) != 0) {
    USB_SERIAL.println("FAILED!");
    while(1) delay(1000);
  }
  USB_SERIAL.println("SUCCESS!");

  // Turn off LEDs for stealth operation
  sensor.configLEDLight(DFRobot_HumanDetection::eFALLLed, 1);

  USB_SERIAL.println("=================================");
  USB_SERIAL.println("System ready! Monitoring for falls...\n");

  startTime = millis();
}

void loop() {
  // Check WiFi connection
  if (WiFi.status() != WL_CONNECTED) {
    USB_SERIAL.println("WiFi disconnected! Reconnecting...");
    connectWiFi();
  }

  unsigned long currentTime = millis();

  // Collect and upload data at specified interval
  if (currentTime - lastDataTime >= DATA_INTERVAL) {
    lastDataTime = currentTime;
    collectAndUploadData();
  }
}

void connectWiFi() {
  USB_SERIAL.print("Connecting to WiFi: ");
  USB_SERIAL.print(WIFI_SSID);
  USB_SERIAL.print("... ");

  WiFi.begin(WIFI_SSID, WIFI_PASSWORD);

  int attempts = 0;
  while (WiFi.status() != WL_CONNECTED && attempts < 30) {
    delay(500);
    USB_SERIAL.print(".");
    attempts++;
  }

  if (WiFi.status() == WL_CONNECTED) {
    USB_SERIAL.println(" CONNECTED!");
    USB_SERIAL.print("IP Address: ");
    USB_SERIAL.println(WiFi.localIP());
  } else {
    USB_SERIAL.println(" FAILED!");
    USB_SERIAL.println("Please check WiFi credentials in config.h");
  }
}

void collectAndUploadData() {
  // Build JSON string with all sensor data
  String jsonData = buildSensorJSON();

  // Print JSON to serial for debugging
  USB_SERIAL.println("Data collected:");
  USB_SERIAL.println(jsonData);

  // Upload to Supabase with retry logic
  bool uploadSuccess = false;
  for (int attempt = 0; attempt < RETRY_ATTEMPTS && !uploadSuccess; attempt++) {
    if (attempt > 0) {
      USB_SERIAL.print("Retry attempt ");
      USB_SERIAL.print(attempt);
      USB_SERIAL.println("...");
      delay(RETRY_DELAY);
    }

    USB_SERIAL.print("Uploading to Supabase... ");
    int httpCode = db.insert(SUPABASE_TABLE, jsonData, false);

    if (httpCode == 201) {
      USB_SERIAL.println("SUCCESS!");
      uploadSuccess = true;
      uploadFailCount = 0;
    } else {
      USB_SERIAL.print("FAILED! HTTP Code: ");
      USB_SERIAL.println(httpCode);
      uploadFailCount++;
    }
  }

  if (!uploadSuccess) {
    USB_SERIAL.print("Upload failed after ");
    USB_SERIAL.print(RETRY_ATTEMPTS);
    USB_SERIAL.println(" attempts.");
    USB_SERIAL.print("Total consecutive failures: ");
    USB_SERIAL.println(uploadFailCount);
  }

  USB_SERIAL.println();
}

String buildSensorJSON() {
  String json = "{";

  // Metadata
  json += "\"device_id\":\"" + String(DEVICE_ID) + "\",";
  json += "\"location\":\"" + String(LOCATION) + "\",";
  json += "\"sensor_mode\":\"fall_detection\",";
  json += "\"uptime_sec\":" + String((millis() - startTime) / 1000) + ",";

  // --- FALL DETECTION MODE DATA ---

  // Human Detection
  uint16_t existence = sensor.dmHumanData(DFRobot_HumanDetection::eExistence);
  uint16_t motion = sensor.dmHumanData(DFRobot_HumanDetection::eMotion);
  uint16_t bodyMove = sensor.dmHumanData(DFRobot_HumanDetection::eBodyMove);
  uint16_t seatedDistance = sensor.dmHumanData(DFRobot_HumanDetection::eSeatedHorizontalDistance);
  uint16_t motionDistance = sensor.dmHumanData(DFRobot_HumanDetection::eMotionHorizontalDistance);

  json += "\"human_existence\":" + String(existence) + ",";
  json += "\"motion_detected\":" + String(motion) + ",";
  json += "\"body_movement\":" + String(bodyMove) + ",";
  json += "\"seated_distance_cm\":" + String(seatedDistance) + ",";
  json += "\"motion_distance_cm\":" + String(motionDistance) + ",";

  // Fall Detection
  uint16_t fallState = sensor.getFallData(DFRobot_HumanDetection::eFallState);
  uint16_t fallBreakHeight = sensor.getFallData(DFRobot_HumanDetection::eFallBreakHeight);
  uint16_t staticResidency = sensor.getFallData(DFRobot_HumanDetection::estaticResidencyState);
  uint16_t fallSensitivity = sensor.getFallData(DFRobot_HumanDetection::eFallSensitivity);

  json += "\"fall_state\":" + String(fallState) + ",";
  json += "\"fall_break_height_cm\":" + String(fallBreakHeight) + ",";
  json += "\"static_residency\":" + String(staticResidency) + ",";
  json += "\"fall_sensitivity\":" + String(fallSensitivity) + ",";

  // Fall Timing
  uint32_t fallTime = sensor.getFallTime();
  uint32_t residencyTime = sensor.getStaticResidencyTime();

  json += "\"fall_time_sec\":" + String(fallTime) + ",";
  json += "\"static_residency_time_sec\":" + String(residencyTime) + ",";

  // Installation Parameters
  uint16_t installHeight = sensor.dmGetInstallHeight();
  json += "\"install_height_cm\":" + String(installHeight) + ",";

  // Trajectory Tracking (X, Y coordinates)
  uint16_t trackX = 0;
  uint16_t trackY = 0;
  sensor.track(&trackX, &trackY);

  json += "\"track_x\":" + String(trackX) + ",";
  json += "\"track_y\":" + String(trackY) + ",";

  // Track Frequency
  uint32_t trackFreq = sensor.trackFrequency();
  json += "\"track_frequency_hz\":" + String(trackFreq);

  json += "}";
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

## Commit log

2026-02-01 Initial commit of moveOmeter IoT elderly monitoring project
    Includes project documentation, Arduino ESP32-C6 test code for mmWave sensor communication, electrical schematics, and pitch deck materials. Large binary files excluded per GitHub size limits.
    [geophone_frontend (1).kicad_sch, geophone_frontend.kicad_sch, geophone_frontend_v2.kicad_sch]
2026-02-02 Add comprehensive data collection system with online configuration
    Implements dual-timer data collection, online device configuration, real-time
    web dashboard, and complete database schema for moveOmeter IoT monitoring.
    Major features:
    - Dual-timer data collection (1s quick position/fall + 10s full sensor data)
    - Online configuration system via Supabase (operational mode, sensitivity, thresholds)
    - NTP time synchronization with UTC storage for accurate timestamps
    - Real-time web dashboard with Chart.js showing position maps and sensor metrics
    - Database schema for device management (moveometers, models, config history)
    - Hardware schematic with MOSFET power control for sensor reset capabili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
    [Arduino_mmWave_serialpassthrough.ino, mmWave_FallDetection_collector.ino, mmWave_Supabase_collector.ino]
2026-02-03 Add configurable sampling rates and 12-hour timeline to dashboard
    Major Features:
    - Configurable sampling rates for fall detection and sleep modes via web UI
    - 12-hour activity timeline visualization at bottom of dashboard
    - Real-time OTA firmware update system
    - Device command system for remote reconfiguration
    Database Changes:
    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
2026-02-03 Add configurable sensor query timing and data collection modes
    New Features:
    - Remote configuration of mmWave sensor query intervals and timing
    - Three supplemental data collection modes: Rotating, All, None
    - Query retry logic with configurable attempts and delays
    - Per-query delays for sensors that need settling time
    - Enable/disable supplemental data collection dynamically
    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
2026-02-03 Add interactive annotation system for timeline events
    Complete Features:
    - User-friendly UI for creating custom timeline annotations
    - Database storage for persistent annotations
    - Visual display on 12-hour timeline alongside auto-detected events
    - Edit and delete functionality for existing annotations
    - Color-coding and emoji icons for visual identification
    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
2026-02-03 Fix 12-hour timeline chart update and add debug logging
    Bug Fixes:
    - Restored missing chart.update() call after setting timeline data
    - Timeline was not refreshing because update call was removed during annotation integration
    - Chart data now properly updates before annotations are applied
    Debug Improvements:
    - Added console logging to track timeline buffer size
    - Log time range of loaded data
    - Display activity data range (min/max values)
    - Show sample data point for verification
    - Warnings when buffer is empty or no data found
    - Better error tracking for data loading
    This fixes the issue where:
    - Timeline showed all values as 30
    - Chart wasn't displaying 12-hour history
    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
2026-02-03 Improve 12-hour timeline data loading with comprehensive debugging
    Enhancements:
    - Better logging of data query range (shows exact 12-hour window)
    - Display total data points available (all modes) before filtering
    - Show actual data span in hours (may be less than 12 if device just started)
    - Log first, middle, and last data points for verification
    - Display activity calculation for sample points
    - Show min/max/avg activity statistics
    - Better error messages when no data found
    Debug Output Now Shows:
    - Query time range (from X to Y)
    - Total data points in database (all modes)
    - Filtered data points for current mode
    - Actual time span of available data
    - First and last data point details
    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
2026-02-03 Enhance timeline historical data loading with comprehensive debugging
    Improvements:
    - Enhanced loadHourlyData() with detailed debug logging matching load12HourData()
    - Shows exact time ranges, data counts, and span duration for both timelines
    - Updated refreshTimelineData() to refresh BOTH 1-hour and 12-hour timelines
    - Added refresh button to 1-hour chart for manual historical data reload
    - Both timelines now properly load full historical data from database on page load
    - Comprehensive console output helps diagnose data loading issues
    User-facing changes:
    - Both timeline views show full historical data from Supabase, not just live data
    - Manual refresh button available on both 1-hour and 1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
2026-02-03 Add comprehensive debugging for flat timeline issue
    Added detailed logging to diagnose why 12-hour timeline appears flat:
    - Log first 3 sample data points with all sensor fields
    - Show activity calculation for first 5 points with formula breakdown
    - Check for unique values in activity data
    - Warn if all values are the same (flat line cause)
    - Warn if all values are 0 (device not collecting data)
    - Log chart data being set to identify issues
    This will help identify:
    1. Missing or null data fields
    2. All sensor readings being 0
    3. Wrong sensor mode being used
    4. Data not varying over time
2026-02-03 Fix flat timeline by removing mode filtering on 12-hour data
    CRITICAL FIX: Timeline was filtering out all data that didn't match current dashboard mode.
    Changes:
    - Remove sensor_mode filtering from load12HourData() query
    - Timeline now loads ALL data from last 12 hours regardless of mode
    - Activity calculation uses each data point's individual sensor_mode
    - Added logging to show what modes exist in the loaded data
    This fixes the "flat line" issue where:
    - User has data in database from 11am onwards
    - Data is in different sensor_mode than current dashboard mode
    - All data was being filtered out, leaving empty timeline
    Timeline now correctly shows all activity from last 12 hours.
    Co-Author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
2026-02-03 Add automatic mode change annotations to timeline
    Features:
    - Shows initial sensor mode at start of timeline
    - Annotates every mode change between sleep and fall_detection
    - Visual indicators with mode-specific colors:
    - Purple (😴 Sleep Mode)
    - Orange (🚨 Fall Detection)
    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
2026-02-11 Add comprehensive project documentation and AI agent guide
    Created complete documentation suite for moveOmeter project:
    Documentation:
    - README.md - Main project overview with quick start guide
    - PROJECT_STATUS.md - Complete status of all features and progress
    - ROADMAP.md - Detailed 6-12 month development plan with priorities
    - AI_AGENT_GUIDE.md - Comprehensive guide for AI coding assistants
    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
2026-02-11 Update README.md with GitHub-optimized overview
    Created public-facing README for GitHub repository with:
    - Compelling tagline and project badges
    - Problem/solution framing
    - Visual emoji-based sections
    - Tech stack badges (Supabase, PostgreSQL, ESP32, etc.)
    - Screenshot placeholders
    - Use cases for different audiences
    - Contributing guidelines
    - Security and privacy highlights
    - Cost breakdown by scale
    - Project stats and metrics
    Sections Added:
    - The Problem / Our Solution
    - Key features with categories
    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
2026-02-11 Fix timeline graphs: drop to zero at gaps instead of ending mid-air
    - Modified addGapBreaks() function in both 12-hour and 24-hour timelines
    - Changed gap handling from inserting null values to inserting zero values
    - Lines now drop to zero when data is missing instead of creating gaps
    This provides clearer visualization of data gaps and periods of inactivity.
    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
2026-02-11 Add DPS310 pressure sensor for door detection (Option A: Event Detection)
    Hardware Integration:
    - Added Adafruit DPS310 barometric pressure sensor support
    - I2C connection at address 0x77
    - Samples at 10 Hz (every 100ms) for fast door detection
    Firmware Changes (mmWave_Supabase_collector.ino):
    - Added Adafruit_DPS310 library include
    - Initialize DPS310 in setup() with high precision config
    - Sample pressure continuously in loop() at 10 Hz
    - Detect door events when pressure changes > 0.3 hPa threshold
    - Track: current pressure, max change, and event count per interval
    - Upload data every 20 seconds with other sensor data
    - Reset counters after successful upload
    - Added pressure data to keep-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
    [mmWave_Supabase_collector.ino]
2026-02-27 Add BLE WiFi provisioning and complete Flutter mobile app
    Firmware changes:
    - Implement BLE GATT server for zero-touch WiFi provisioning
    - Add NVS storage for WiFi credentials persistence
    - Add keep-alive ping system (30s intervals) for accurate online/offline detection
    - Support automatic BLE mode when no WiFi configured
    - Add fall detection timing configuration (fall_time, residence_time, residence_switch)
    Flutter app features:
    - Complete mobile app with device list and detail pages
    - BLE device scanning and WiFi configuration flow
    - Real-time sensor data visualization (presence, movement, fall detection)
    - Activity-based offline detection (65s threshold)
    - Comprehensive error handling wi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
    [DPS310_pressure_test.ino, ble_provisioning.cpp, mmWave_Supabase_collector.ino]
2026-02-27 Fix BLE device name display - show advertised name instead of BLE stack name
    Previously showed "nimble" (the ESP32 BLE stack name) instead of the actual
    advertised device name like "moveOmeter-009CDA".
    - Add DiscoveredDevice class to store both device and advertised name
    - Update scanForDevices() to extract advName from advertisementData
    - Pass advertised name to WiFiConfigPage for proper display
    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
2026-02-27 Fix UI overflow in scan devices page scanning indicator
    Reduce CircularProgressIndicator size from 20x20 to 16x16 and spacing from 16 to 12
    to prevent 22 pixel overflow on smaller iPhone screens.
2026-02-27 Add serial command interface for WiFi credential management
    New serial commands via USB Serial Monitor:
    - CLEAR_WIFI / RESET_WIFI: Clear NVS credentials and reboot into BLE mode
    - STATUS: Show device info (firmware, WiFi, IP, MAC, mode, uptime)
    - RESTART / REBOOT: Restart the device
    - HELP / ?: Show all available commands
    Commands are case-insensitive and echo characters for feedback.
    Useful for testing, debugging, and factory reset scenarios.
    [mmWave_Supabase_collector.ino]
2026-02-27 Add periodic BLE scanning every 10 seconds
    Instead of continuous scanning, now scans in intervals:
    - Scan for 5 seconds
    - Show results
    - Pause for 5 seconds
    - Repeat
    Benefits:
    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
2026-02-27 Stop BLE scanning when navigating to WiFi config & fix text field taps
    1. Stop periodic scanning when user taps a device
    - Prevents BLE interference during WiFi provisioning
    - Saves battery
    - Restarts scanning when returning to scan page
    2. Remove custom onTap handlers from text fields
    - Let iOS handle TextField taps natively
    - Should fix the "second tap required" issue
    - Keep FocusNodes for programmatic navigation
2026-02-27 Allow empty WiFi passwords for open networks
    Updated validation to support open WiFi networks:
    - Password field now optional (labeled "WiFi Password (optional)")
    - Hint text: "Leave blank for open networks"
    - Validation only checks password length if password is provided
    - Updated both UI and BLE service validation
    This allows provisioning devices on networks without passwords.
2026-03-03 Add landing page and deployment script
    - New landing page at pictureFrame/software/landing_page/index.html
    - Deployment script to move dashboard to /dashboard/ subdirectory
    - Landing page served at / with Login button pointing to /dashboard/
    - Creates backup before deployment
    - Sets proper permissions and reloads nginx
    Landing page: http://moveometer.com/
    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
2026-03-03 Add Resend API integration for waitlist
    Landing page updates:
    - Updated waitlist form to submit via API
    - Added JavaScript for async form submission
    - Shows success/error messages
    - Improved UX with loading states
    Backend API:
    - Created Node.js endpoint for waitlist management
    - Integrates with Resend API to add contacts to audience
    - CORS enabled for cross-origin requests
    - Email validation and error handling
    Deployment:
    - Automated deployment script for waitlist API
    - PM2 process manager setup
    - Nginx reverse proxy configuration
    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
    [moveOmeterV1.kicad_pcb, moveOmeterV1.kicad_sch]
2026-03-03 Update Login button to redirect to login page
    Changed Login button from /dashboard/ to /dashboard/login.html
    to show proper login screen instead of directly accessing dashboard.
    Dashboard is already protected by auth-guard.js which:
    - Checks user authentication
    - Redirects to login.html if not authenticated
    - Verifies user profile and role
    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
2026-03-05 Update landing page messaging
    Replace "HIPAA-Ready Privacy" with "Open Source Hardware" and soften
    "impossible choice" to "difficult choice" for more accurate positioning.
2026-03-12 Add device settings, fix time format persistence, update landing page content
    Mobile App Improvements:
    - Add device settings page with room name editing and sensor tuning parameters
    - Human detection thresholds (seated/motion distance)
    - Fall detection timing (sensitivity, fall time, residence time)
    - Sampling intervals for all modes
    - Fix 12-hour/24-hour time format persistence across all pages
    - Make "Today's Activity" section clickable to view full 24-hour detail
    - Fix room name persistence when edited in settings
    - Change device list to show "Last motion:" with actual time from daily metrics
    - Add day detail page for viewing historical 24-hour data
    Landing Page Updates:
    - Update "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
    [SEN0623.step, moveOmeterV1.kicad_pcb, moveOmeterV1.kicad_sch]
2026-03-12 Add house-level summary and test data generation
    Database:
    - Add SQL script to generate 3 test moveOmeters with realistic sample data
    - Generate 7 days of sensor data for bedroom, bathroom, and kitchen
    - Auto-calculate daily aggregates for test devices
    - Add TEST_DATA_README.md with instructions
    Flutter App:
    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
2026-03-12 Fix: Add device_type_id to test device creation
    - Query device_types table to get moveometer type ID
    - Include device_type_id in all INSERT statements
    - Add validation to ensure device type exists before creating devices
2026-03-13 Fix: Show device online status regardless of sensor mode
    The activity timestamp query was filtering by sensor_mode, causing the
    app to show devices as offline (pink bars) even when data was being
    received. This happened when there was a mismatch between the device's
    configured operational_mode and the actual sensor_mode in the data.
    - Remove sensor_mode filter from fetchActivityTimestamps()
    - Add comment explaining why we don't filter by mode
    - Activity detection now works regardless of sensor mode
    This fixes the issue where devices appear offline in the app's 'Last Hour'
    view even though they're actively sending data.
    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
2026-03-13 Fix: Remove sensor_mode filters from all data queries
    The app was filtering all sensor data by sensor_mode, causing it to show
    no data (pink offline boxes) when the device's operational_mode didn't
    match the sensor_mode in the actual data.
    - Remove sensor_mode filter from fetchLastHourData()
    - Remove sensor_mode filter from fetch24HourData()
    - All data from device now shows regardless of mode
    This is a temporary fix. The real solution (per user feedback) is to move
    all data processing and status calculations to the server side, so clients
    just display pre-computed values from the database.
    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
2026-03-13 Fix: Handle null device_timestamp in activity detection
    The device sends records with null device_timestamp, but the app was
    filtering these out, causing it to show as offline even though data
    was being received.
    - Use created_at instead of device_timestamp for filtering
    - Fall back to created_at when device_timestamp is null
    - Remove .not('device_timestamp', 'is', null) filter
    This matches the website behavior and correctly detects device activity.
    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
2026-03-13 Fix: Add SECURITY DEFINER to device status trigger
    The trigger was failing with 'permission denied for table users' because
    it was running with the inserting user's permissions, which couldn't access
    tables referenced by RLS policies on moveometers.
    SECURITY DEFINER makes the trigger run with the function owner's permissions
    (postgres/superuser), bypassing RLS restrictions.
    This fixes the issue where all sensor data inserts were being blocked by
    the trigger permission errors.
2026-03-13 Phase 2: Remove client-side status logic from mobile app
    Mobile app now reads device status directly from database instead of
    calculating it client-side.
    - Added _loadDeviceStatus() to fetch connection_status from database
    - Removed _activityTimestamps (no longer needed)
    - Simplified _deviceOnlineStatus to just read from database
    - Removed all offline period calculation logic (~50 lines)
    - Removed gap detection for activity timestamps
    - Removed offline period visual overlays from chart
    - Removed 'Offline' from chart legend
    - Added connection_status, seconds_since_last_data, quality_score fields
    The app is now a pure display client - all status logic is server-side.
    Co-Authored-By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
2026-03-13 Phase 2: Remove client-side status logic from web dashboard
    Web dashboard now reads device status directly from database instead of
    - Replaced checkDeviceOnlineStatus() with database query
    - Removed lastDataTimestamp variable (no longer needed)
    - Removed all threshold constants (20s, 60s)
    - Removed timestamp comparison logic
    - Status now comes from moveometers.connection_status field
    - Function reads seconds_since_last_data from database
    The web dashboard is now a pure display client - all status logic is
    server-side.
    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
2026-03-25 Fix BLE provisioning, WiFi handling, and device status monitoring
    Major improvements to ESP32 firmware and iOS app reliability:
    ESP32 Firmware:
    - Fix BLE provisioning acknowledgement (deferred credential processing)
    - Remove WiFi credential auto-deletion on connection failure
    - Add tiered WiFi reconnection intervals (10s → 20s → 30s)
    - Process BLE writes in main loop to avoid blocking acknowledgements
    iOS App:
    - Fix Bluetooth initialization delays on scan page
    - Fix WiFi permission checking (handle iOS permission states)
    - Remove WiFi scanning on iOS (platform limitation)
    - Fix device status display (show connection_status not device_status)
    Infrastructure:
    - Add Supabase Edge Functio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
    [ble_provisioning.cpp, mmWave_Supabase_collector.ino]
2026-04-18 Web dashboard: stability fixes, analytics, caretaker management (Apr 13)
    - Fixed critical memory leaks (intervals and realtime subscriptions not cleaned up)
    - Added offline device visual indicators (red overlay on timeline graphs)
    - Added exponential backoff retry for database queries (3 attempts)
    - Added offline/reconnect detection via window online/offline events
    - Fixed auth flow to use absolute paths (/login.html) and redirect to /dashboard.html
    - Moved dashboard to dashboard.html; index.html restored as public landing page
    - Added analytics.js with error handling (won't crash if CDN fails)
    - Added caretaker_management.js for caretaker assignment features
    - Added analytics initialization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
2026-04-18 Hardware: KiCad PCB v1 updates, hardware v0.01 files, new part libraries
    - Update moveOmeterV1 schematic and PCB layout
    - Add STEP export files (moveOmeterV1.step, moveOmeterV1_fused.step)
    - Remove stale lock files and auto-saved backup files
    - Add hardware version 0.01 files (2026-04-06)
    - Add Adafruit ESP32-C6 and Eagle KiCad part libraries
    [2026_04_06_pictureFrame_unitMeterv0.01.stl, 2026_04_06_pictureFrame_unitMeterv0.02.stl, 2026_04_06_pictureFrame_v0.01.3mf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]
2026-04-18 Firmware: mmWave collector updates; add ESP32 NVS diagnostic tool; update landing page
    - mmWave_Supabase_collector: additional fixes following BLE/WiFi provisioning work
    - Add ESP32_NVS_Diagnostic: utility sketch to read/debug NVS (non-volatile storage) on device
    - Update stillKicking landing page content
    [ESP32_NVS_Diagnostic.ino, mmWave_Supabase_collector.ino]
2026-04-18 Fix: convert Adafruit-Eagle-Library.kicad from gitlink to plain files
    Was accidentally tracked as an embedded git repo (gitlink). Removed nested
    .git directory so the library files are now regular tracked files.
2026-08-21 PCB v0.1: fabrication files for JLCPCB order YP1746215 (ordered 2026-06-07)
    Gerbers + drill files exported 2026-06-07, 4-layer moveOmeterV1 board,
    plus matching 3D STEP export. These are the exact files sent to fab.
    [moveOmeterV1-B_Cu.gbr, moveOmeterV1-B_Mask.gbr, moveOmeterV1-B_Paste.gbr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]
